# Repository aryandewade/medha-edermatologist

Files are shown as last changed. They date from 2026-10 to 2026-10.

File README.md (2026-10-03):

# Medha E-Dermatologist (Mobile Spacer Edition)

AI-assisted skin disease screening using standard smartphones fitted with an inexpensive 3D-printed optical spacer.

| File | Purpose |
|---|---|
| [prd.md](prd.md) | Product requirements: mobile-first user flow, clinical targets, triage priorities |
| [design.md](design.md) | UI/UX design: single-column mobile layout, spacer framing guide, touch controls |
| [architecture.md](architecture.md) | System architecture: mobile PWA, HTTPS ingress (Cloudflare Tunnel), FastAPI backend |
| [methodology.md](methodology.md) | ML methodology: EfficientNet-B0, mobile augmentations, calibration, triage rules |
| [data-plan.md](data-plan.md) | Clinical datasets (SCIN, Fitzpatrick17k, PAD-UFES-20, DDI), 6-class schema, collection protocol |
| [image-processing.md](image-processing.md) | Preprocessing details: quality gate, colour constancy, lesion localization, glare mitigation |
| [hardware-spacer.md](hardware-spacer.md) | Specifications for the 3D-printed optical spacer, phone cradle, hygiene, and reference patch |
| [api-spec.md](api-spec.md) | REST API contract between mobile PWA and backend (`/predict`, `/health`) |
| [testing-evaluation.md](testing-evaluation.md) | Test strategy, subgroup fairness evaluation, and demo-day hardware checklist |
| [setup-and-deployment.md](setup-and-deployment.md) | Local development setup, Cloudflare Tunnel HTTPS guide, mobile phone configuration |
| [ethics-and-safety.md](ethics-and-safety.md) | Mobile privacy, EXIF/GPS stripping, informed consent, triage ethics |
| [roadmap.md](roadmap.md) | Phased execution plan: mobile spacer first, USB dermatoscope multimodal later |

---

## One-Paragraph Summary
A frontline community health worker opens the web app on their smartphone over secure HTTPS, attaches a 3D-printed optical spacer to the phone's primary camera, places it flush against the patient's skin, and taps **Capture & Analyze**. The backend verifies sharpness and illumination, applies automatic colour constancy, localizes the central skin lesion, and evaluates a calibrated EfficientNet-B0 classifier across 6 classes: **Eczema, Psoriasis, Tinea (Ringworm), Acne, Healthy Skin, and Suspicious Lesions**. High-risk suspicious lesions immediately trigger an urgent specialist referral banner, while ambiguous or low-confidence presentations trigger an honest "uncertain, please consult a dermatologist" advisory.

---

## Read Order for New Team Members
`prd.md` ➔ `hardware-spacer.md` ➔ `image-processing.md` ➔ `architecture.md` ➔ `methodology.md` ➔ `roadmap.md`

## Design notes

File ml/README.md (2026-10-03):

# 6-Class Skin Disease Classifier (EfficientNet-B0)

Mobile-spacer skin screening: EfficientNet-B0 trained on smartphone + 3D-printed
optical spacer captures, with reference-patch colour calibration and calibrated
clinical triage.

## Supported Classes (6)
1. **Eczema** (Atopic Dermatitis)
2. **Psoriasis**
3. **Tinea** (Ringworm / fungal infection)
4. **Acne**
5. **Healthy Skin**
6. **Suspicious Lesion** (neoplastic / pre-cancerous — urgent referral)

---

## Workflow Architecture

```
[Smartphone + 3D-Printed Spacer]
          ↓
   Mobile PWA Capture (HTTPS)
          ↓
   Image Preprocessing
┌──────────────────────────────────────┐
│ • Quality Check (Blur / Glare / Illum)│
│ • Optional ROI Crop (Center Square)  │
│ • Resize to 224 × 224                │
│ • ImageNet Normalize                 │
└──────────────────┬───────────────────┘
                   ↓
         EfficientNet-B0 Backbone
          (ImageNet Pretrained)
                   ↓
      Custom Classifier Head
      (Dropout 0.3 + Linear 1280→6)
                   ↓
       6 Calibrated Output Classes
 ┌──────────┬───────────┬────────┬────────┬────────────┬──────────────────────┐
 ↓          ↓           ↓        ↓        ↓            ↓                      ↓
Eczema  Psoriasis   Tinea    Acne   Healthy   Suspicious Lesion     [Triage / Abstain]
```

---

## File Structure

- [`model.py`](src/model.py): `SkinDiseaseEfficientNetB0` PyTorch architecture with custom 6-class head and feature extraction.
- [`preprocess.py`](src/preprocess.py): Quality gate (Laplacian blur, glare, brightness), reference-patch colour constancy + Shades-of-Gray fallback, ROI cropping, 224x224 normalization.
- [`reference_patch.py`](src/reference_patch.py): 18% gray reference-patch locator + white balance (adaptive neutrality vs. skin baseline).
- [`inference.py`](src/inference.py): End-to-end triage engine (quality -> colour -> localization -> calibrated inference -> referral rules).
- [`dataset.py`](src/dataset.py): Dataset loader with mobile-appropriate augmentations and inverse class weighting.
- [`train.py`](src/train.py): Two-stage transfer learning (frozen warmup + unfrozen fine-tuning with cosine decay).
- [`calibrate.py`](src/calibrate.py): Temperature scaling (NLL fit + ECE) -> writes `backend/models/temperature.json`.
- [`eval.py`](src/eval.py): Per-class Precision/Recall/Macro-F1, confusion matrix (CSV+PNG), Top-3 accuracy, ECE, Fitzpatrick subgroup audit.
- [`data_harmonize.py`](src/data_harmonize.py): Ingest SCIN/Fitzpatrick17k/PAD-UFES-20 -> 6 canonical classes, pHash dedupe, group-safe stratified split + manifest.
- [`export_onnx.py`](src/export_onnx.py): ONNX model exporter for high-speed CPU inference.
- [`classes.yaml`](../configs/classes.yaml): Configuration defining class labels, colors, and clinical uncertainty thresholds.

---

## Quick Usage

All commands run from the `ml/` directory.

### 1. Harmonize datasets into the 6 canonical classes
```bash
python src/data_harmonize.py \
  --fitzpatrick_dir raw/fitzpatrick17k \
  --scin_dir raw/scin \
  --pad_dir raw/pad-ufes-20 \
  --local_dir raw/spacer_captures \
  --out_dir data --dedupe
```

### 2. Train / Fine-tune
Organize (or let step 1 produce) the dataset as:
```
data/
  train/<class>/*.jpg
  val/<class>/*.jpg
  test/<class>/*.jpg
```
Then run:
```bash
python src/train.py --train_dir data/train --val_dir data/val --finetune_epochs 20
```

### 3. Calibrate (temperature scaling)
```bash
python src/calibrate.py --checkpoint models/best_model.pt --val_dir data/val
```
Writes `backend/models/temperature.json`; the inference engine loads it automatically.

### 4. Evaluate (metrics + confusion matrix + fairness)
```bash
python src/eval.py --checkpoint models/best_model.pt --test_dir data/test --output_dir reports
```

### 5. Export to ONNX (for fast CPU inference)
```bash
python src/export_onnx.py --checkpoint models/best_model.pt --output models/model.onnx
```

### Reference-patch calibration (standalone check)
```bash
python src/reference_patch.py --image sample_capture.jpg
```

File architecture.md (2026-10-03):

# System Architecture (Mobile-First)

## 1. Overview
The architecture is designed as a **mobile-first client-server system**. A smartphone running a Progressive Web App (PWA) captures skin images through a 3D-printed optical spacer. The image and capture metadata are transmitted securely over HTTPS to a FastAPI inference backend that executes automated quality checks, colour constancy, lesion localization, model inference, and clinical triage rules.

```
+---------------------------------------+
|  Smartphone + 3D-Printed Spacer       |
|  Mobile Browser (React + Vite PWA)    |
|  - Rear camera (facingMode: environ)  |
|  - Live circular reticle & guide      |
|  - Canvas frame snapshot              |
+---------------------------------------+
                   │
                   │ POST /api/v1/predict
                   │ (Multipart JPEG + modality metadata)
                   │ Over HTTPS (Cloudflare Tunnel / ngrok / Cloud)
                   ▼
+-------------------------------------------------------+
|  FastAPI Backend Server                               |
|                                                       |
|  1. Ingestion & Validation (file type, size, EXIF)   |
|  2. Quality Gate (Laplacian blur, lighting, glare)    |
|  3. Colour Normalization (Gray-World / Patch balance) |
|  4. Lesion Localization (ROI crop & center-framing)   |
|  5. Preprocessing (Resize 224×224, ImageNet norm)     |
|  6. Inference Engine (ONNX Runtime / PyTorch)         |
|  7. Calibration & Uncertainty (T-scaling, OOD)        |
|  8. Clinical Triage Rules (Referral / Abstention)     |
|  9. Explainability (Grad-CAM++ heatmap overlay)       |
+-------------------------------------------------------+
                   │
                   │ JSON Result + Base64 Heatmap
                   ▼
+---------------------------------------+
|  Mobile Results View                  |
|  - Condition card & confidence score  |
|  - Top-3 differential breakdown       |
|  - Triage Referral Banner             |
|  - Heatmap visual overlay             |
+---------------------------------------+
```

---

## 2. Components & Responsibilities

| Component | Technology | Primary Responsibility |
|---|---|---|
| **Mobile Web Client** | React, Vite, Tailwind CSS, Lucide Icons | Touch-friendly camera feed, spacer framing guide, one-thumb capture, instant results display. |
| **Secure Ingress / Tunnel** | Cloudflare Tunnel / ngrok / Caddy HTTPS | Provides valid public SSL/TLS certificate required by mobile browsers for camera API access. |
| **API Server** | FastAPI, Uvicorn, Pydantic v2 | Endpoint orchestration, request validation, logging, and error handling. |
| **Quality Module** | OpenCV (`cv2`) | Fast assessment of motion blur, darkness, saturation, and reference patch detection. |
| **Colour & ROI Module** | OpenCV, NumPy | Colour constancy (Shades of Gray), background/spacer ring exclusion, and lesion bounding crop. |
| **Inference Engine** | ONNX Runtime (CPU) / PyTorch | High-throughput, low-latency evaluation of the trained EfficientNet-B0 network. |
| **Calibration Module** | NumPy, SciPy | Post-hoc temperature scaling ($T$) ensuring reliable, clinically calibrated probabilities. |
| **Triage Rules Engine** | Python | Maps probability vector to actionable clinical guidance (`ok`, `uncertain`, `urgent`). |
| **Explainability Engine**| PyTorch Grad-CAM | Generates morphological activation heatmaps confirming model attention. |

---

## 3. Data Flow (Single Mobile Capture)

1. **Client Capture:** User aligns the spacer flush against the skin. The video frame is snapped at native sensor resolution and encoded to JPEG (quality 0.92).
2. **Payload Submission:** `POST /api/v1/predict` sends:
   - `image`: Image binary (multipart/form-data)
   - `modality`: `"mobile_spacer"` (or `"dermatoscope"` in later phases)
   - `device_info`: Mobile handset model and browser agent
   - `capture_height_mm`: Distance from lens to skin (e.g. `35.0`)
3. **Quality Validation:** OpenCV computes Laplacian variance and mean brightness. If blurred or poorly lit, returns HTTP 422 with actionable guidance (e.g., `"Hold spacer steady against skin"`).
4. **Colour Normalization:** Calculates illumination cast using Gray-World or calibrated reference patch and standardizes color temperature across varied environments.
5. **Lesion Localization & ROI Cropping:** Identifies central lesion region, crops out the dark circular spacer borders, and resizes to $224 \times 224$ pixels.
6. **Inference & Calibration:** Evaluates ONNX model to produce raw logits $z_i$, then computes calibrated probabilities $p_i = \text{softmax}(z_i / T)$.
7. **Triage Assessment:**
   - If $P(\text{suspicious\_lesion}) \ge 0.25 \implies$ `urgent` triage alert.
   - If $\max_i P(i) < 0.50$ or $(P_1 - P_2) < 0.10 \implies$ `uncertain` triage alert.
   - Otherwise $\implies$ `ok` triage with condition name and reassurance advice.
8. **Client Display:** Renders triage alert banner, condition details, and top-3 distribution directly on the mobile screen.

---

## 4. Hosting & Network Topologies

Because **mobile browsers strictly forbid camera access on unencrypted HTTP connections** (except `localhost`, which a phone cannot access on an external machine), the hosting topology requires an HTTPS endpoint:

```
[Phone on 4G/Wi-Fi] 
         │
         ▼ (HTTPS: https://medha-demo.trycloudflare.com)
[Cloudflare Tunnel / ngrok Ingress]
         │
         ▼ (HTTP localhost:8000)
[FastAPI Backend on Dev Laptop]
```

| Deployment Mode | Ingress Strategy | Best Suited For |
|---|---|---|
| **Local Development with Phone** | **Cloudflare Tunnel (`cloudflared tunnel --url http://localhost:8000`)** or **ngrok** | Rapid live testing on physical smartphone with zero server cost. |
| **Local Wi-Fi Network** | Self-signed SSL certificate with local DNS or mkcert | Offline environments without active internet connection. |
| **Demo Day / Production** | Cloud Run or Render container with custom domain and managed SSL | High-reliability backup for hackathon jury evaluation. |

---

## 5. Configuration Architecture (`configs/classes.yaml`)

```yaml
modality: mobile_spacer
version: "v2.0-mobile"

classes:
  - id: eczema
    label: "Eczema"
    name: "Atopic Dermatitis / Eczema"
    severity: "common"
    color: "#2563EB"
  - id: psoriasis
    label: "Psoriasis"
    name: "Psoriasis"
    severity: "common"
    color: "#D97706"
  - id: tinea
    label: "Tinea"
    name: "Tinea / Fungal Ringworm"
    severity: "common"
    color: "#7C3AED"
  - id: acne
    label: "Acne"
    name: "Acne Vulgaris"
    severity: "common"
    color: "#059669"
  - id: healthy
    label: "Healthy Skin"
    name: "Normal Skin"
    severity: "normal"
    color: "#10B981"
  - id: suspicious_lesion
    label: "Suspicious Lesion"
    name: "Atypical / Neoplastic Lesion"
    severity: "urgent"
    color: "#DC2626"

thresholds:
  uncertain_max_prob: 0.50
  margin_min_prob: 0.10
  urgent_suspicious_prob: 0.25
  blur_min_laplacian_var: 55.0
  brightness_range: [40, 225]
  glare_max_ratio: 0.12
```

---

## 6. Security, Privacy & Data Protection

- **No EXIF Footprint:** Smartphone cameras embed exact GPS coordinates, timestamps, and device identifiers. The backend immediately strips all EXIF metadata in memory upon receiving the byte stream.
- **In-Memory Volatility:** Images are processed entirely within RAM buffers (`io.BytesIO`) and discarded upon request completion unless explicit user consent is flagged for model refinement.
- **Origin Isolation:** Strict CORS middleware allowing only the authorized frontend web origin.

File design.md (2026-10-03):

# Mobile UI/UX Design (Smartphone + 3D Spacer)

## 1. Design Principles
1. **One-Thumb Operation:** Primary actions (capture, retry, review) positioned in the natural thumb zone at the bottom of the screen.
2. **Physical-Digital Alignment:** Clear visual overlays guide the health worker to position the 3D spacer flush against the patient's skin.
3. **Clinical Triage Clarity:** Results emphasize triage action (Self-care/Monitor, Specialist Review, Urgent Referral) rather than raw disease probabilities.
4. **Resilient to Field Conditions:** Clear, actionable feedback on poor focus, inadequate light, or tilted spacer placement.

---

## 2. Mobile Screen Layout (Single-Column Vertical Flow)

```
+---------------------------------------+
|  [Logo] E-Dermatologist   [EN/HI/MR]  |
+---------------------------------------+
|                                       |
|  [Live Camera Viewfinder]             |
|   ┌─────────────────────────────┐     |
|   │       (  ( O )  )           │     |
|   │   Circular Spacer Reticle   │     |
|   │   & Lesion Framing Ring     │     |
|   │                             │     |
|   │ [• Ref Patch OK] [• Light OK]│    |
|   └─────────────────────────────┘     |
|                                       |
|  [Instructions Card]                  |
|  "Place spacer flat against skin.     |
|   Center the lesion inside circle."   |
|                                       |
|  [ CAPTURE & ANALYZE ] (Large Button) |
|  [ ⚡ Test Link ]   [ 📁 Upload Photo]|
+---------------------------------------+
|                                       |
|  [Triage Referral Banner]             |
|  🚨 URGENT REFERRAL RECOMMENDED       |
|                                       |
|  [Condition Summary Card]             |
|  Suspicious Lesion (78.4% Confidence) |
|                                       |
|  [Differential Distribution (Top-3)]  |
|  ■ Suspicious Lesion  78.4%           |
|  ■ Actinic / Psoriasis 14.1%          |
|  ■ Normal / Healthy    7.5%           |
|                                       |
|  [Analyzed Image with Heatmap Toggle] |
|                                       |
|  [ 📄 Export Referral Summary PDF ]   |
+---------------------------------------+
|  Footer: "Screening tool only. Not a  |
|  medical diagnosis. Consult doctor."  |
+---------------------------------------+
```

---

## 3. Core Mobile Components

| Component | Visual Presentation & Behavior |
|---|---|
| **Viewfinder & Spacer Reticle** | Full-width 4:3 or 1:1 camera feed showing a circular translucent framing ring matching the inner diameter of the 3D spacer cone. |
| **Placement & Lighting Chips** | Real-time visual status pills floating over the live feed: <br>• **Focus:** Green (`Sharp`) vs Amber (`Defocused - Press flush`) <br>• **Light:** Green (`Illumination OK`) vs Red (`Too dark`) <br>• **Reference Patch:** Green (`Patch Detected`) |
| **Primary Capture CTA** | Prominent floating action bar at bottom screen ($56\text{ px}$ height) with haptic feedback vibration on capture. |
| **Camera Selector (Streamlined)** | Automatically selects rear camera (`facingMode: environment`). An unobtrusive lens switch icon appears only if multiple rear lenses (e.g. macro vs wide) are detected. |
| **Instructions Bottom Sheet** | Expandable card explaining three-step physical placement: 1. Clean spacer contact rim. 2. Place flat against skin. 3. Tap Capture. |
| **Triage Alert Banners** | • **Urgent (Red):** `Possible serious or neoplastic lesion. Refer to dermatologist promptly.` <br>• **Uncertain (Amber):** `Image uncertain or ambiguous. Reposition spacer or consult doctor.` <br>• **Common Condition (Blue):** `Features consistent with [Condition]. Primary care management.` <br>• **Healthy (Green):** `No active lesion detected.` |
| **Heatmap & Contrast Slider** | Shows the preprocessed skin image with a toggleable Grad-CAM++ morphological activation overlay. |

---

## 4. UI States & Field Error Handling

| Scenario | User-Facing Guidance & Remediation |
|---|---|
| **Camera Permission Blocked** | Screen overlay explaining how to enable camera permissions in mobile browser settings. |
| **Tilted Spacer (Light Leak)** | Amber alert: *"Spacer not flat on skin. Light leakage detected. Press evenly against skin."* |
| **Motion Blur (Hand Shake)** | Red alert: *"Blurry capture. Rest arm on flat surface and hold phone steady."* |
| **Analyzing Pipeline** | Pulsing radial progress indicator with label: *"Normalizing colour and analyzing..."* (Buttons disabled). |
| **Offline / Network Interruption** | Offline cache badge: *"Unable to reach server. Check connection or tap Retry."* |
| **Gallery Upload Fallback** | Subordinate link beneath capture button allowing selection of existing photo from mobile camera roll. |

---

## 5. Visual Styling & Mobile Ergonomics

- **Palette:** Clinical Trust theme. Deep navy header (`#0F172A`), clean off-white background (`#F8FAFC`), crisp high-contrast cards (`#FFFFFF`).
- **Severity Semantic Colors:**
  - Urgent Referral: Crimson (`#DC2626`)
  - Review / Common: Cobalt Blue (`#2563EB`)
  - Healthy Skin: Emerald Green (`#059669`)
  - Warning / Uncertain: Warm Amber (`#D97706`)
- **Typography:** System sans-serif (`Inter`, `-apple-system`, `Roboto`) for instantaneous rendering on mobile devices.
- **Accessibility:**
  - Minimum touch targets of $48 \times 48\text{ px}$ across all interactive buttons.
  - WCAG AAA contrast ratio ($\ge 7:1$) on triage advisory text.
  - Dynamic type support for larger font sizes.

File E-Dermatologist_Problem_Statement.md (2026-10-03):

# E-Dermatologist: Skin Disease Screening System

**Hackathon:** Somaiya Vidyavihar University, K J Somaiya School of Engineering  
**Clinical Partner:** Kaushalya Hospital  
**Document Type:** Problem statement and project brief (Mobile Spacer Edition)

---

## 1. Problem Statement

Access to dermatologists is severely restricted across rural and semi-urban India. Frontline community health workers (such as ASHA workers and local nurses) encounter high volumes of unmanaged or misidentified skin conditions, while patients often travel vast distances or delay care for months until manageable conditions worsen or malignant lesions advance.

Build a low-cost, mobile-first **AI skin disease screening and clinical triage system** that pairs standard **smartphones with an inexpensive 3D-printed optical spacer**. A health worker attaches the spacer to their phone camera, places it flush against the patient's skin, and captures a standardized close-up photo. The system checks capture sharpness, normalizes illumination and colour, localizes the lesion, and reports the likely condition category, confidence score, and top-3 differential breakdown to facilitate immediate primary care management or expedited referral to a dermatologist.

---

## 2. Objectives

1. Enable **instant mobile browser screening** on standard smartphones via a responsive Progressive Web App over secure HTTPS.
2. Standardize photographic capture using an accessible, **3D-printed focal spacer** that eliminates hand tremor focus shifts and standardizes distance.
3. Classify skin images across **common outpatient conditions** (Eczema, Psoriasis, Tinea, Acne), **Healthy Skin**, and a dedicated **Suspicious Lesion** triage class.
4. Normalize real-world lighting variations using automated **colour constancy** and reference patch calibration.
5. Provide **honest clinical triage guidance**: flag suspicious lesions for urgent referral and abstain on ambiguous or low-confidence cases.
6. Serve as an accessible **screening and triage decision aid**, explicitly complementing rather than replacing medical doctors.

---

## 3. Supported Clinical Classes

| Category | Conditions Included | Primary Triage Recommendation |
|---|---|---|
| **Inflammatory** | Eczema (Atopic Dermatitis), Psoriasis, Acne Vulgaris | Primary clinic management / Symptom monitoring |
| **Fungal Infection** | Tinea (Ringworm / Dermatophytosis) | Antifungal treatment / Hygiene guidance |
| **Normal Baseline** | Healthy Skin | Reassurance |
| **High-Risk Lesions** | Suspicious Neoplastic Lesions (Melanoma, BCC, SCC, Actinic Keratosis) | **Urgent Dermatologist Referral & In-Person Review** |

*(Future Phase: Specialized Dermatoscope Modality for fine-grained sub-classification of melanocytic and non-melanocytic lesions).*

---

## 4. Scope

**In Scope:**
- Mobile-first web interface (PWA) with live viewfinder framing guide.
- Standardized capture with 3D-printed spacer and reference colour patch.
- Secure HTTPS tunneling (Cloudflare Tunnel) connecting mobile phones to the backend.
- Backend image processing pipeline: blur/glare quality gate, colour constancy, lesion localization.
- Multi-class classification via fine-tuned EfficientNet-B0.
- Confidence calibration (Temperature Scaling) and urgent referral rules.
- Morphological explainability via Grad-CAM++ activation heatmaps.

**Out of Scope (Hackathon Prototype):**
- Definitive clinical diagnosis or automated prescription dispensing.
- Invasive cancer staging or replacing dermatopathological biopsy.
- Long-term Electronic Medical Record (EMR) persistent storage.
- Ultra-rare skin pathologies outside the supported taxonomy.

---

## 5. Hardware Specifications

| Item | Specification | Status |
|---|---|---|
| **Smartphone** | Standard rear autofocus camera (e.g. 12MP+ sensor, iOS or Android) | Required (Primary) |
| **3D-Printed Spacer** | Fixed 35 mm focal height, matte-black non-reflective interior, phone clip | Required (Primary) |
| **Reference Patch** | Dual 18% neutral gray & 90% white patch with 5 mm scale bar | Required (Primary) |
| **Hygiene Supplies** | 70% isopropyl alcohol sanitization wipes for spacer contact rim | Required |
| **Laptop / Compute** | 8 GB+ RAM for running backend inference (CPU inference via ONNX) | Required |
| **Network Ingress** | Cloudflare Tunnel or ngrok providing public HTTPS endpoint | Required |
| **USB Dermatoscope** | Handheld UVC microscope camera (for secondary multimodal phase) | Phase 2 Extension |

---

## 6. Software Stack

- **Frontend:** React, Vite, Tailwind CSS, HTML5 Canvas API, Mobile WebRTC (`getUserMedia`).
- **Networking:** Cloudflare Tunnel (`cloudflared`) / ngrok for mobile HTTPS camera access.
- **Backend:** FastAPI (Python 3.10+), Uvicorn, Pydantic v2.
- **Image Processing & Vision:** OpenCV (`cv2`), NumPy, SciPy (colour constancy, Otsu segmentation, Laplacian sharpness).
- **ML Framework & Serving:** PyTorch, Torchvision, ONNX Runtime (CPU-optimized), Albumentations.

---

## 7. System Workflow

```
[Smartphone + 3D Spacer] ──(HTTPS)──> [FastAPI Backend]
                                             │
                                  ├─ 1. Quality Validation (Blur, light, glare)
                                  ├─ 2. Colour Constancy (Shades of Gray)
                                  ├─ 3. Lesion Localization (ROI square crop)
                                  ├─ 4. EfficientNet-B0 ONNX Inference
                                  ├─ 5. Calibrated Triage Rules
                                  └─ 6. Grad-CAM++ Morphological Overlay
                                             │
                                      (JSON Result)
                                             ▼
                             [Mobile Results & Referral View]
```

---

## 8. Disclaimer
This software is a screening decision-support aid and does not constitute a definitive medical diagnosis. All patients presenting with persistent, worsening, or suspicious skin lesions must be referred to a qualified dermatologist.

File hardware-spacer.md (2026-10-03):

# Hardware Specification: 3D-Printed Optical Spacer

## 1. Purpose & Physical Rationale

Standard smartphone cameras cannot reliably photograph close-up skin lesions because:
1. **Uncontrolled Focal Distance:** Hand tremor and micro-movements cause autofocus hunting, yielding blurred captures.
2. **Variable Illumination & Glare:** Direct camera flash causes harsh specular reflection (white hot spots) that obscures lesion pigment networks and texture.
3. **Scale Ambiguity:** Without a physical scale reference, machine learning models cannot discern the true physical dimensions of a lesion (e.g., a 2 mm macule vs. a 15 mm patch).

The **3D-Printed Optical Spacer** physically clips onto the smartphone to establish a **fixed, repeatable optical focal plane**, control ambient illumination, and present a calibrated scale and colour reference in every capture.

---

## 2. Spacer Design Specifications

```
             [Smartphone Body]
        ═══════════════════════════
                 [Lens]
                   │  (Aperture Ø 14 mm)
           ┌───────┴───────┐
           │   Top Collar  │
           │               │
           │  Conical Tube │  ◄── Matte Black Interior
           │  (Height:     │      (Roughness Ra > 3.2 µm)
           │   35 mm)      │
       ┌───┴───────────────┴───┐
       │   Contact Ring Flange │  ◄── Radius 24 mm
       │ [Ref Patch] [5mm Bar] │
       └───────────────────────┘
        ═══════════════════════════
               [Patient Skin]
```

### Physical Dimensions
- **Focal Height ($H$):** $35.0\text{ mm}$ (optimal for standard smartphone wide lenses having a minimum focus distance of $50\text{–}70\text{ mm}$ with $1.5\times$ digital macro framing, or $35\text{ mm}$ for lenses with near-macro autofocus).
- **Optional Stackable Rings:** Modular $5\text{ mm}$ snap-fit extension rings to adjust total focal height from $30\text{ mm}$ to $50\text{ mm}$ depending on the specific handset camera module.
- **Top Camera Aperture:** $14.0\text{ mm}$ diameter, oversized to clear multi-lens camera bumps without vignetting.
- **Base Skin Contact Diameter:** $48.0\text{ mm}$ outer diameter ($38.0\text{ mm}$ inner clear aperture) to capture adequate lesion margins.

---

## 3. Optical & Lighting Control

- **Matte-Black Interior Wall:**
  - The interior conical surface must feature a **dead-matte black finish** to eliminate internal specular reflections and barrel flaring.
  - Sliced with internal concentric micro-grooves ($0.2\text{ mm}$ step height) to trap grazing-angle light rays.
- **Ambient Lighting Ports:**
  - Includes two angled, translucent diffuser side windows ($45^\circ$ angle of incidence) covered with white diffusion film.
  - Allows ambient clinic room light to illuminate the lesion softly and uniformly while completely blocking direct glare and shadowing from the phone handset.
- **Flash Lockout:** The spacer collar physically occludes the smartphone's built-in LED flash to prevent accidental flash blinding.

---

## 4. Materials, Hygiene & Biocompatibility

- **Filament Material:** **PETG** (Polyethylene Terephthalate Glycol) or **Medical-Grade PLA**.
  - High chemical resistance against alcohol and disinfectants.
  - Biocompatible for transient non-broken skin contact (ISO 10993 compliant).
- **Sanitization Protocol:**
  - The skin-contact flange must be thoroughly wiped with a **70% Isopropyl Alcohol (IPA)** disinfectant wipe before and after every patient contact.
  - PETG maintains dimensional integrity and does not craze or degrade after repeated alcohol wipe exposure.
- **Wall Thickness:** $2.0\text{ mm}$ minimum to guarantee mechanical rigidity and prevent ambient light bleeding through the plastic walls.

---

## 5. Calibrated Reference Patch Integration

Mounted flush along the interior lower rim of the contact aperture:
1. **18% Neutral Gray Card Segment:** Provides ground-truth neutral reflectance for automatic white balance and colour constancy algorithms.
2. **90% Reflective White Patch:** Defines maximum dynamic range and detects LED overexposure.
3. **5 mm High-Contrast Scale Bar:** Alternating black/white $1.0\text{ mm}$ millimeter ticks enabling pixel-to-millimeter spatial calibration.

---

## 6. Phone Cradle & Handset Compatibility

The spacer mounts to the handset via an adjustable spring-loaded clamping bracket or model-specific snap-on phone case:

| Phone Model | Primary Lens Position | Min. Focus Distance | Recommended Spacer Height |
|---|---|---|---|
| **Samsung Galaxy S22 / S23 / S24** | Center-left top lens (50MP 1x wide) | $45\text{ mm}$ | $35\text{ mm}$ (with $1.2\times$ crop) |
| **iPhone 13 / 14 / 15 (Standard)** | Bottom-left lens (1x wide) | $50\text{ mm}$ | $35\text{ mm}$ |
| **iPhone 13 / 14 / 15 Pro** | Bottom-left lens (locked to 1x wide) | $40\text{ mm}$ (disable macro auto-switch) | $35\text{ mm}$ |
| **OnePlus 11 / 12 / Nord** | Upper central circular cluster | $50\text{ mm}$ | $40\text{ mm}$ |
| **Google Pixel 7 / 8** | Horizontal camera bar (left lens) | $45\text{ mm}$ | $35\text{ mm}$ |

---

## 7. 3D Print Settings (FDM / SLA)

```ini
Layer Height: 0.16 mm (for smooth internal micro-grooves)
Infill Density: 100% (Solid, to block light transmission)
Perimeters / Shells: 4
Material: Black PETG (Matte preferred)
Nozzle Temp: 235°C
Bed Temp: 75°C
Supports: None required (designed with 45° overhang angle)
Post-Processing: Wipe interior with isopropyl alcohol; apply matte black acrylic spray if glossy filament was used.
```

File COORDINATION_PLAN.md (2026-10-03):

# Dual-Agent Simultaneous Development & Coordination Plan

**Project:** E-Dermatologist (Mobile Spacer Edition)  
**Coordination Strategy:** Strict modular separation with immutable interface contracts to enable simultaneous, conflict-free development.

---

## 1. Modular Division of Labor

```
┌─────────────────────────────────────────────────────────────┐
│                    SHARED CONTRACTS                         │
│  • configs/classes.yaml (Class Schema & Thresholds)         │
│  • api-spec.md          (REST API Data Contracts)           │
│  • models/model.onnx    (Shared Model Weights Artifact)     │
└──────────────────────────────┬──────────────────────────────┘
                               │
               ┌───────────────┴───────────────┐
               ▼                               ▼
┌──────────────────────────────┐┌──────────────────────────────┐
│  AGENT 1: ANTIGRAVITY        ││  AGENT 2: PARTNER AGENT      │
│  (Frontend, UX & Reporting)  ││  (ML, Vision & Hardware)     │
├──────────────────────────────┤├──────────────────────────────┤
│ • Mobile PWA UI & Viewfinder ││ • Data Harmonization (SCIN/  │
│ • i18n (EN, HI, MR strings)  ││   Fitzpatrick17k/PAD-UFES)   │
│ • PDF Referral Report Export ││ • Reference Patch CV Module  │
│ • Backend /report Endpoint   ││ • Temperature Calibration (T)│
│ • Client State & History     ││ • Evaluation Script & Matrix │
│ • Touch Ergonomics & Audio   ││ • 3D CAD Spacer STL Generator│
└──────────────────────────────┘└──────────────────────────────┘
```

---

## 2. Strict File Ownership Matrix

Neither agent should edit files owned by the other without explicit coordination.

| Subsystem / Directory | Owner | Permitted Actions |
|---|---|---|
| `frontend/src/**` | **Agent 1 (Antigravity)** | Read/Write (Components, styling, i18n, PDF export) |
| `backend/app/services/report.py` | **Agent 1 (Antigravity)** | Read/Write (ReportLab PDF generation service) |
| `ml/src/data_harmonize.py` | **Agent 2 (Partner)** | Read/Write (Dataset downloading and label mapping) |
| `ml/src/calibrate.py` | **Agent 2 (Partner)** | Read/Write (Temperature scaling optimization) |
| `ml/src/eval.py` | **Agent 2 (Partner)** | Read/Write (Confusion matrix, subgroup fairness) |
| `ml/src/reference_patch.py` | **Agent 2 (Partner)** | Read/Write (OpenCV reference patch locator) |
| `hardware/**` | **Agent 2 (Partner)** | Read/Write (3D print CAD, STL generators, scale bars) |
| `configs/classes.yaml` | **SHARED (Frozen)** | Read-Only unless mutually agreed in this document |
| `backend/app/routers/predict.py`| **SHARED (Careful)** | Agent 1 owns `/report`; Agent 2 integrates CV patch |

---

## 3. Simultaneous Task Schedule

### Agent 1 (Antigravity) Work Queue:
- [x] **Task 1.1:** Build `backend/app/services/report.py` using ReportLab to generate a clean, 1-page clinical referral PDF.
- [x] **Task 1.2:** Add `POST /api/v1/report` endpoint to `backend/app/routers/predict.py` returning binary PDF.
- [x] **Task 1.3:** Implement Hindi (`hi`) and Marathi (`mr`) full translation dictionaries in `frontend/src/i18n.ts`.
- [x] **Task 1.4:** Connect the **PDF Export** button in `ResultsDashboard.tsx` to download the generated report.
- [x] **Task 1.5:** Add local session history drawer (allowing health workers to review previous captures).

### Agent 2 (Partner Agent) Work Queue:
- [x] **Task 2.1:** Create `ml/src/data_harmonize.py` to ingest and map SCIN, Fitzpatrick17k, and PAD-UFES-20 into the 6 canonical classes.
- [x] **Task 2.2:** Build `ml/src/reference_patch.py` using OpenCV template/color matching to locate the 18% gray patch in the spacer margin.
- [x] **Task 2.3:** Build `ml/src/calibrate.py` to optimize temperature $T$ on validation logits and output `backend/models/temperature.json`.
- [x] **Task 2.4:** Build `ml/src/eval.py` computing per-class Precision, Recall, Macro-F1, and Confusion Matrix.
- [x] **Task 2.5:** Create `hardware/spacer_generator.py` (or OpenSCAD script) generating parameterized 35mm optical spacer STL models.

---

## 4. Live Status Tracker

| Task ID | Description | Assigned To | Status | Notes |
|---|---|---|---|---|
| **1.1** | ReportLab PDF referral generator service | Agent 1 (Antigravity) | `COMPLETED` | Generates 1-page PDF summary |
| **1.2** | `POST /api/v1/report` backend endpoint | Agent 1 (Antigravity) | `COMPLETED` | Endpoint verified with HTTP 200 |
| **1.3** | Hindi & Marathi i18n dictionaries | Agent 1 (Antigravity) | `COMPLETED` | Dynamic EN/HI/MR switcher active |
| **1.4** | PDF export button integration in React UI | Agent 1 (Antigravity) | `COMPLETED` | One-touch PDF download |
| **1.5** | Session history drawer in mobile UI | Agent 1 (Antigravity) | `COMPLETED` | Stores last 8 captures in session |
| **2.1** | `ml/src/data_harmonize.py` mapping pipeline | Agent 2 (Partner) | `COMPLETED` | 6-class label map, pHash dedupe, group-safe stratified split, manifest |
| **2.2** | `ml/src/reference_patch.py` locator | Agent 2 (Partner) | `COMPLETED` | Adaptive gray-patch WB; integrated into `preprocess.py` + `inference.py` + `/predict` |
| **2.3** | `ml/src/calibrate.py` temperature scaling | Agent 2 (Partner) | `COMPLETED` | ECE + scipy T-fit; writes `backend/models/temperature.json`; loaded by engine |
| **2.4** | `ml/src/eval.py` metrics and matrix | Agent 2 (Partner) | `COMPLETED` | Precision/Recall/Macro-F1, CM (CSV+PNG), Top-3, ECE, Fitzpatrick audit |
| **2.5** | 3D spacer parametric CAD script | Agent 2 (Partner) | `COMPLETED` | `hardware/spacer_generator.py` + `spacer.scad`; watertight STL in `hardware/stl/` |

---

## 5. Clean Interface Contracts for Agent 2

To start work immediately without conflicts, Agent 2 should follow these exact interfaces:

### Interface 1: Reference Patch Detector (`ml/src/reference_patch.py`)
```python
def detect_and_calibrate_patch(image_bgr: np.ndarray) -> Tuple[np.ndarray, bool, Dict[str, Any]]:
    """
    Returns:
      corrected_bgr: Normalized image array
      patch_found: True if 18% gray patch was located on spacer margin
      metrics: {"gray_deviation": float, "patch_coords": [x, y, w, h]}
    """
```

### Interface 2: Temperature Calibration Output (`backend/models/temperature.json`)
```json
{
  "temperature": 1.25,
  "ece_before": 0.124,
  "ece_after": 0.038,
  "calibrated_at": "2026-10-03"
}
```

### Interface 3: Hardware CAD (`hardware/`)
Create `hardware/spacer_generator.py` or `.scad` to output STL files into `hardware/stl/`.

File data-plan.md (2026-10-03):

# Data Plan (Mobile Spacer-First)

## 1. Class Set (Mobile Clinical Profile)

The classification schema focuses on common outpatient conditions treatable at primary health centers, plus a healthy skin baseline and a critical referral category for suspicious neoplastic lesions.

| ID | Condition / Category | Primary Clinical Sources | Triage Action |
|----|---|---|---|
| `eczema` | Eczema (Atopic Dermatitis) | DermNet, Fitzpatrick17k, SCIN, SD-198 | Primary care treatment / Monitor |
| `psoriasis` | Psoriasis | DermNet, Fitzpatrick17k, SCIN, SD-198 | Primary care treatment / Specialist triage |
| `tinea` | Tinea (Ringworm / Fungal) | DermNet, Fitzpatrick17k, SCIN | Antifungal treatment / Monitor |
| `acne` | Acne Vulgaris | DermNet, Fitzpatrick17k, SCIN, SD-198 | Primary care treatment |
| `healthy` | Healthy Skin | Own spacer captures, normal skin regions | Reassurance |
| `suspicious_lesion` | Suspicious Lesion (Melanoma, BCC, SCC, Actinic Keratosis) | DDI, PAD-UFES-20, Fitzpatrick17k, SCIN | **Urgent Dermatologist Referral** |

*Note on `suspicious_lesion`:* Rather than forcing a mobile phone camera to reliably sub-classify subtle histological differences between early melanoma, nodular BCC, and invasive SCC without dermoscopy, these high-risk neoplastic and pre-malignant lesions are pooled into a single high-sensitivity referral class. A specialized dermatoscope modality can be added later for deep lesion subtyping.

---

## 2. Source Datasets (Clinical & Smartphone Photography)

Dermoscopy datasets (HAM10000, ISIC) are replaced with clinical and smartphone macro photography datasets reflecting realistic mobile optical characteristics:

| Dataset | Modality & Description | Key Assets | Considerations & Caveats |
|---|---|---|---|
| **Fitzpatrick17k** | Clinical & patient-captured skin photos | 16,577 images labeled with condition and Fitzpatrick skin type (FST I–VI) | Atlases web-scraped; labels have minor noise; deduplicate carefully |
| **SCIN (Google)** | Smartphone photos crowdsourced in real-world settings | Real mobile sensors, diverse lighting, includes healthy/mild cases | Free-form framing; requires lesion cropping and quality filtering |
| **PAD-UFES-20** | Smartphone cameras (various models) | 2,298 clinical images with biopsy labels and patient metadata | Includes smartphone photos of suspicious lesions and inflammatory diseases |
| **DDI (Diverse Dermatology Images)** | Clinical photography from Stanford | High-quality clinical photos across Fitzpatrick I–VI with biopsy ground truth | Excellent benchmark for fairness and suspicious lesion sensitivity |
| **DermNet NZ** | Clinical photography atlas | Extensive visual coverage of inflammatory and fungal conditions | Check licensing; resolution varies; standard clinical perspective |
| **SD-198** | Clinical digital photography | 198 disease classes, 6,585 images | Good supplemental source for acne, eczema, and psoriasis variations |
| **Own Spacer Captures** | Smartphone + 3D-printed spacer + reference patch | Exact hardware domain target for calibration and validation | Primary benchmark for model selection, thresholding, and demo stability |

---

## 3. Label Harmonization & Mapping

1. **Master Dictionary (`ml/data/label_map.csv`):** Maps thousands of raw source tags into the 6 canonical target IDs (`eczema`, `psoriasis`, `tinea`, `acne`, `healthy`, `suspicious_lesion`).
2. **Suspicious Lesion Grouping:**
   - Includes: Melanoma, Basal Cell Carcinoma (BCC), Squamous Cell Carcinoma (SCC), Actinic Keratosis (AK), Atypical/Dysplastic Nevi with malignant suspicion.
   - Excludes: Benign regular nevi, seborrheic keratosis, and common freckles (filtered or routed to healthy/benign where verified).
3. **Ambiguity Handling:** Any image with conflicting multi-disease tags or low diagnostic confidence is discarded.

---

## 4. Data Cleaning & Normalization Pipeline

1. **Perceptual Deduplication:** Run perceptual hashing (pHash and dHash, Hamming distance $\le 4$) across all merged datasets to eliminate duplicates and near-identical crops that could bridge train and test sets.
2. **Artifact & Non-Skin Rejection:** Automatically detect and discard images with non-skin subjects, watermarks, intrusive text, or black borders.
3. **Lesion Localization & Standardized Cropping:**
   - Detect skin ROI and center crop/crop around lesion bounding boxes.
   - Standardize aspect ratios to prevent unnatural stretching.
4. **Colour & Illumination Normalization:**
   - Apply Gray-World or Shades-of-Gray colour constancy to correct varied hospital/room lighting casts before training.

---

## 5. Dataset Splits

| Split | Proportion | Splitting Strategy |
|---|---|---|
| **Train** | 70% | Stratified by class and grouped by patient/source ID to prevent data leakage. |
| **Validation** | 15% | Used for hyperparameter tuning, early stopping, and temperature scaling calibration. |
| **Public Test** | 15% | Held out for benchmark evaluation. |
| **Real Spacer Test Set** | Separate (Held-out) | Real photos captured with the project smartphone and 3D spacer. Serves as the ultimate ground-truth decision gate. |

---

## 6. Real-Camera Spacer Data Collection Protocol

To eliminate domain shift and calibrate the mobile model on the physical hardware:

### Hardware Setup
- **Smartphone:** Standardized test model (e.g., primary camera, 1x focal length, autofocus locked/set to spacer height, flash disabled, ambient room lighting or internal spacer diffuse LED).
- **3D-Printed Spacer:** Fixed height (e.g., 35 mm distance from camera lens to skin plane), matte-black non-reflective interior.
- **Reference Patch:** A calibrated dual-color/gray reference ring (18% neutral gray, 90% white patch, and 5 mm scale bar) mounted at the spacer contact perimeter to calibrate scale and white balance.

### Collection Procedure
1. **Healthy Skin Targets:**
   - Minimum 100 captures across 10+ diverse individuals covering Fitzpatrick types III to VI.
   - Body sites: Inner forearm, outer arm, dorsal hand, cheek, forehead, neck.
   - 3 captures per site (repositioned between shots).
2. **Clinical Lesions (Hospital Collaboration):**
   - Conducted exclusively under clinician supervision at Kaushalya Hospital.
   - **Mandatory written informed consent** signed before capturing.
   - Record anonymous metadata: Unique ID, age band, sex, anatomical site, clinician ground truth, Fitzpatrick skin type, and reference patch visibility.
3. **Sanitization:** Disinfect the spacer contact ring with hospital-grade 70% isopropyl alcohol wipes between every patient.
4. **Data Hygiene:** Strip all EXIF metadata, GPS coordinates, device serial numbers, and timestamp identifiers before ingest into the training/eval folders.

---

## 7. Class Balance Targets & Bias Auditing

- **Training Distribution Target:** Aim for at least 800 training samples per class; floor of 300 samples for the `suspicious_lesion` cluster.
- **Class Imbalance Strategy:** Use inverse frequency class weighting and Focal Loss ($\gamma = 2.0$) to avoid bias toward frequent inflammatory conditions.
- **Fairness & Subgroup Audits:**
  - Evaluate accuracy, recall, and calibration error across Fitzpatrick skin type buckets: Fair (I–II), Intermediate (III–IV), and Deeply Pigmented (V–VI).
  - Safety requirement: Recall for `suspicious_lesion` must remain $\ge 0.90$ across all available skin-tone cohorts.

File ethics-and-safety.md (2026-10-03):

# Ethics, Safety, and Responsible AI Use (Mobile Spacer Edition)

## 1. Clinical Intended Use
E-Dermatologist is an **AI-assisted screening and triage decision-support tool** intended for use by trained frontline health workers. It is **not** a diagnostic device, does not prescribe medications, and does not replace in-person consultation with a qualified dermatologist.

---

## 2. Patient Privacy & Data Hygiene on Mobile Handsets

Capturing clinical photographs using mobile smartphones introduces privacy challenges requiring strict controls:

1. **Immediate EXIF & GPS Stripping:**
   - Smartphone camera sensors automatically attach high-precision GPS coordinates, exact timestamps, handset serial numbers, and device hardware signatures.
   - The system immediately strips all EXIF metadata in memory before parsing pixel arrays. No geographic or device data is retained or logged.
2. **Zero-Local-Footprint Default:**
   - Captured frames are held temporarily in the browser canvas and transmitted over HTTPS in volatile memory.
   - Images are **never saved to the smartphone's native camera roll or photo gallery**, preventing accidental exposure on personal or shared clinic devices.
3. **In-Memory Server Processing:**
   - The backend server processes image streams directly in RAM (`io.BytesIO`). No patient photos are written to server disks unless the patient has explicitly signed an IRB-approved consent form for model improvement.
4. **Third-Party Isolation:**
   - Patient photographs are never transmitted to external commercial vision APIs or cloud language models.

---

## 3. Informed Consent Protocol for Mobile Photography

Whenever taking skin photographs for screening or evaluation:

- **Verbal Explanation:** The health worker must explain in the patient's primary language that the phone camera with the plastic spacer will take a close-up photo of the affected skin patch to assist with screening.
- **Voluntary Participation:** The patient must be informed that screening is completely voluntary and refusal will not compromise their care.
- **Personal Phone Safeguard:** If health workers utilize personal mobile devices in the field, they must use the secure web client rather than taking standard photos via their phone camera app.

---

## 4. Safety Architecture & Clinical Referral Guidance

| Clinical Scenario | System Triage Wording | Clinical Action Required |
|---|---|---|
| **Suspicious Neoplastic Lesion** | *"Morphological features warrant formal in-person examination by a dermatologist. Facilitate prompt referral."* | Expedited clinic appointment at Kaushalya Hospital; avoid premature biopsy or delay. |
| **Common Inflammatory / Fungal** | *"Features consistent with [Condition]. Consider clinical confirmation and primary care management."* | Primary clinic treatment protocol (e.g. topical emollients, antifungals). |
| **Ambiguous / Borderline** | *"Uncertain presentation. Please consult a dermatologist for manual examination."* | Abstains from guessing; prevents false reassurance or incorrect self-medication. |
| **Healthy Skin** | *"No active inflammatory or suspicious lesion detected."* | Patient reassurance. |

*Absolute Wording Rule:* The interface must **never** state *"You have [Disease]"* or *"Diagnosis: [Disease]"*. All findings are phrased as screening suggestions.

---

## 5. Algorithmic Fairness & Bias Mitigation

- **Skin Tone Diversity:** Benchmark performance across Fitzpatrick skin types I through VI. Avoid claiming universal accuracy without explicit stratified metrics.
- **Disproportionate Risk:** In deeply pigmented skin (Fitzpatrick V–VI), erythema (redness) often presents as violaceous, brown, or hyperpigmented patches. Training data and evaluation must account for these presentations to avoid under-detecting eczema and psoriasis in Indian patient populations.
- **Model Card Disclosure:** Maintain an open model card documenting dataset distributions, training parameters, subgroup recall, and known failure modes.

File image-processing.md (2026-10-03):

# Digital Image Processing Pipeline (Mobile Spacer Photography)

This document details the complete computer vision and digital image processing pipeline executed prior to model inference. Because frontline smartphone photos suffer from varied illuminants, hand tremors, and skin reflections, this preprocessing sequence transforms noisy field captures into standardized, normalized clinical inputs.

---

## 1. High-Level Processing Architecture

```
Raw Smartphone Frame (JPEG, 12MP / 4032×3024)
                      │
                      ▼
        [Stage 1: Quality Gate & Validation]
        ├─ Laplacian Sharpness (Var ≥ 55.0)
        ├─ Illumination Range ([40, 225])
        ├─ Glare / Specular Hotspot Ratio (≤ 12%)
        └─ Reference Patch Detection
                      │ (PASS)
                      ▼
        [Stage 2: Colour Constancy & Normalization]
        ├─ Shades-of-Gray Illuminant Estimation (p=6)
        └─ Reference Patch Alignment (Gray R=G=B)
                      │
                      ▼
        [Stage 3: Lesion Localization & ROI Segmentation]
        ├─ Spacer Rim & Background Masking
        ├─ Skin Thresholding (YCbCr / HSV)
        ├─ Primary Lesion Bounding Box
        └─ Aspect-Ratio Preserving Square Crop
                      │
                      ▼
        [Stage 4: Tensor Standardization]
        ├─ Bicubic Resize to 224 × 224
        └─ ImageNet Normalization (Mean / Std)
                      │
                      ▼
        To EfficientNet-B0 Backbone (1, 3, 224, 224)
```

---

## 2. Stage 1: Quality Gates & Automated Validation

Images failing physical capture criteria are rejected immediately with actionable guidance before consuming ML inference cycles:

### A. Blur & Defocus Estimation (Laplacian Variance)
The Laplacian operator $\nabla^2 I$ computes the second-order spatial derivatives of pixel intensities:
$$\nabla^2 I = \frac{\partial^2 I}{\partial x^2} + \frac{\partial^2 I}{\partial y^2}$$
Sharp edges exhibit high spatial variance, whereas defocused or motion-blurred frames exhibit low variance:
$$\text{Blur Score} = \text{Var}\left( \nabla^2 I_{\text{gray}} \right) = \frac{1}{N} \sum_{x,y} \left( \nabla^2 I(x,y) - \mu_{\nabla^2} \right)^2$$
- **Threshold:** $\text{Blur Score} \ge 55.0$ (Pass). If $< 55.0$, return HTTP 422: `"Image too blurry. Hold spacer steady against skin."`

### B. Illumination & Dynamic Range
- Convert to grayscale $I_{\text{gray}}$. Calculate mean intensity $\mu_I$.
- **Acceptance Window:** $40 \le \mu_I \le 225$.
- Images $< 40$ are underexposed (insufficient clinic lighting); images $> 225$ are overexposed.

### C. Specular Glare & Reflection Ratio
Moist or oily skin reflects direct light rays, producing blinding saturated white spots ($I \ge 245$ across all channels):
$$\text{Glare Ratio} = \frac{\sum \mathbb{I}(I_{\text{gray}} \ge 245)}{N_{\text{total}}}$$
- **Threshold:** $\text{Glare Ratio} \le 0.12$ ($12\%$). If higher, the user is prompted to tilt the spacer slightly to dissipate direct specular bounce.

---

## 3. Stage 2: Colour Constancy & Illumination Normalization

Smartphone cameras apply proprietary Auto White Balance (AWB) algorithms that alter skin tones under fluorescent, halogen, or warm LED lighting. We apply physical colour constancy to extract the true skin reflectance:

### A. Shades-of-Gray Algorithm
Generalizes the Gray-World ($p=1$) and White-Patch ($p=\infty$) hypotheses using the Minkowski $p$-norm ($p=6$):
$$e_c = \left( \frac{1}{|A|} \int_{x \in A} |I_c(x)|^p dx \right)^{1/p}, \quad c \in \{R, G, B\}$$
The estimated illuminant vector $\mathbf{e} = [e_R, e_G, e_B]$ is normalized to unit length:
$$\hat{\mathbf{e}} = \frac{\mathbf{e}}{\|\mathbf{e}\|}$$
Pixel values are corrected to a neutral daylight illuminant $[1/\sqrt{3}, 1/\sqrt{3}, 1/\sqrt{3}]$:
$$I_c^{\text{corrected}}(x) = I_c(x) \cdot \frac{1}{\sqrt{3} \cdot \hat{e}_c}$$

### B. Reference-Patch White Balance (High-Precision Calibration)
When the calibrated 18% neutral gray patch on the spacer rim is detected:
1. Sample mean pixel intensities $[\bar{R}_{\text{ref}}, \bar{G}_{\text{ref}}, \bar{B}_{\text{ref}}]$ over the patch ROI.
2. Compute gain factors relative to green:
   $$k_R = \frac{\bar{G}_{\text{ref}}}{\bar{R}_{\text{ref}}}, \quad k_G = 1.0, \quad k_B = \frac{\bar{G}_{\text{ref}}}{\bar{B}_{\text{ref}}}$$
3. Scale every pixel: $R' = k_R \cdot R$, $B' = k_B \cdot B$.

---

## 4. Stage 3: Lesion Localization & ROI Segmentation

Digital spacers capture an internal circular field of view bordered by the matte-black spacer flange. We isolate the clinical lesion from the surrounding physical border:

### A. Spacer Ring & Background Masking
- The spacer contact ring creates a known circular aperture centered at $(x_c, y_c)$ with radius $R_{\text{spacer}} \approx 0.45 \cdot \min(H, W)$.
- A binary circular mask $M_{\text{circ}}(x,y)$ zeroes out all pixels outside the aperture, preventing dark plastic borders from confounding the classifier.

### B. Skin & Lesion Segmentation
- Convert the masked RGB image to the $YC_bC_r$ color space.
- Apply empirical skin chrominance constraints:
  $$77 \le C_b \le 127 \quad \text{and} \quad 133 \le C_r \le 173$$
- Calculate morphological Otsu thresholding within the skin region to segment the darker, erythematous, or hyperpigmented lesion area from normal background skin.
- Apply morphological closing (kernel size $5 \times 5$) to bridge small gaps caused by skin pores or fine hairs.

### C. Aspect-Ratio Preserving Square Bounding Crop
- Compute the bounding box $(x_1, y_1, w_{\text{box}}, h_{\text{box}})$ enclosing the largest connected lesion component.
- Expand to a square of side length $S = \max(w_{\text{box}}, h_{\text{box}}) \times 1.25$ (providing a $25\%$ surrounding healthy margin for context).
- If no discrete focal lesion is found (as in widespread eczema or normal healthy skin), default to the central square crop of the clear aperture.

---

## 5. Stage 4: Standardization for Deep Learning

1. **Spatial Resampling:**
   - Crop the segmented square region and downsample to $224 \times 224$ pixels using **Bicubic Interpolation** (`cv2.INTER_CUBIC`), preserving high-frequency textural patterns (e.g. scales, papules, pigment network).
2. **Dynamic Range Scaling:**
   - Convert `uint8` $[0, 255]$ to `float32` $[0.0, 1.0]$.
3. **Statistical Normalization:**
   - Normalize each color channel using ImageNet population statistics:
     $$x_{\text{norm}}^{(c)} = \frac{x^{(c)} - \mu_c}{\sigma_c}$$
     where $\boldsymbol{\mu} = [0.485, 0.456, 0.406]$ and $\boldsymbol{\sigma} = [0.229, 0.224, 0.225]$.
4. **Memory Layout:**
   - Permute channel ordering from OpenCV $(H, W, C)$ to PyTorch Tensor $(1, C, H, W)$.

---

## 6. Execution Latency Profile (Laptop CPU Benchmark)

| Stage | Operation | CPU Latency (Intel i5/i7) |
|---|---|---|
| **Quality Gate** | Grayscale conversion + cv2.Laplacian + pixel sum | $4.2\text{ ms}$ |
| **Colour Constancy** | Shades-of-Gray Minkowski norm ($p=6$) | $12.5\text{ ms}$ |
| **Lesion Segmentation**| Masking + $YC_bC_r$ thresholding + contour box | $8.1\text{ ms}$ |
| **Resampling & Tensor**| Bicubic resize to $224 \times 224$ + standardization | $2.4\text{ ms}$ |
| **Total Pipeline** | **End-to-End Image Processing** | **$\approx 27.2\text{ ms}$** |

The entire preprocessing sequence consumes under **$30\text{ ms}$** per frame on a standard laptop CPU, ensuring instant response times for mobile health workers.

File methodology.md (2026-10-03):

# ML Methodology (Mobile Clinical Profile)

## 1. Task Definition
Automated multi-class screening of macro skin images captured via smartphone cameras fitted with a 3D-printed optical spacer. The model outputs calibrated probabilities across 6 classes:
1. `eczema` (Atopic Dermatitis)
2. `psoriasis` (Psoriasis)
3. `tinea` (Ringworm / Dermatophytosis)
4. `acne` (Acne Vulgaris)
5. `healthy` (Normal Healthy Skin)
6. `suspicious_lesion` (Neoplastic / Pre-cancerous / Atypical Lesions)

---

## 2. Approach: Transfer Learning on EfficientNet-B0

- **Backbone Selection:** `EfficientNet-B0` pretrained on ImageNet-1k. Chosen for exceptional parameter efficiency (5.3M parameters), rapid CPU inference latency ($< 35\text{ ms}$ on laptop/cloud CPU), and strong macro-feature extraction.
- **Classification Head:** 
  $$\text{Embedding (1280)} \longrightarrow \text{Dropout}(p=0.3) \longrightarrow \text{Linear}(1280, 6) \longrightarrow \text{Logits}$$
- **Training Strategy:**
  - **Phase 1 (Warmup):** Freeze backbone feature layers; train custom classifier head for 3 epochs with AdamW ($\text{lr} = 3 \times 10^{-4}$).
  - **Phase 2 (End-to-End Fine-Tuning):** Unfreeze entire backbone for 20–25 epochs using differential learning rates ($\text{lr}_{\text{backbone}} = 5 \times 10^{-5}$, $\text{lr}_{\text{head}} = 2 \times 10^{-4}$), Cosine Annealing learning rate schedule, and Focal Loss ($\gamma = 2.0$) with class weighting.

---

## 3. Preprocessing & Colour Normalization Pipeline

Mobile smartphone cameras exhibit wide variations in auto-white balance, sensor ISP color tuning, and ambient lighting. Images pass through a structured preprocessing sequence:

```
Raw Mobile Capture
       ↓
Quality Gate (Laplacian blur score ≥ 55, Brightness in [40, 225], Glare ≤ 12%)
       ↓
Colour Constancy (Shades-of-Gray / Reference-Patch White Balance)
       ↓
Lesion Localization & ROI Extraction (Crop out spacer ring & peripheral shadows)
       ↓
Resize to 224 × 224 (Bicubic Interpolation)
       ↓
Standardization (ImageNet Mean [0.485, 0.456, 0.406], Std [0.229, 0.224, 0.225])
```

1. **Colour Constancy:**
   - Evaluates the illuminant colour using the **Shades-of-Gray** algorithm (Minkowski $p$-norm $p=6$):
     $$e(x) = \left( \frac{\int |I(x)|^p dx}{\int dx} \right)^{1/p}$$
   - When a calibrated reference patch is visible within the spacer margin, normalizes RGB channels to align the reference patch with neutral gray ($R=G=B$).
2. **Lesion Localization:**
   - Detects skin foreground against the spacer's matte-black contact boundary using Otsu thresholding in $YC_bC_r$ color space.
   - Extracts the bounding box enclosing the primary lesion and applies a symmetric square crop.

---

## 4. Mobile Domain Data Augmentations

Dermatoscope-specific augmentations (circular vignettes, black contact gel bubbles, simulated dermatoscopy hairs) are removed. In their place, we apply augmentations modeling real smartphone camera dynamics using Albumentations:

| Augmentation Type | Operators | Clinical / Physical Rationale |
|---|---|---|
| **Illumination & White Balance** | `ColorJitter`, `RandomToneCurve`, `RGBShift` | Simulates variations in room lighting (fluorescent, warm LED, daylight). |
| **Shadows & Occlusion** | `RandomShadow`, `CoarseDropout` | Models shadows cast by the smartphone body or health worker's hand. |
| **Optics & Motion** | `GaussianBlur`, `DefocusBlur`, `MotionBlur` | Simulates hand instability or slight defocus during phone positioning. |
| **Geometry** | `RandomRotate90`, `Rotate(degrees=180)`, `Affine(scale=(0.85, 1.15))` | Skin lesions have no canonical orientation; accounts for varying phone angles. |
| **Sensor Noise** | `GaussNoise`, `ImageCompression(quality_range=(75, 95))` | Simulates mobile CMOS sensor grain in dim clinic rooms and JPEG compression. |

---

## 5. Calibration & Temperature Scaling

Raw deep learning models are notoriously overconfident. We calibrate output probabilities via post-hoc **Temperature Scaling**:

1. Logits $z = [z_1, \dots, z_6]$ are scaled by a learned scalar parameter $T > 0$:
   $$P_i = \frac{\exp(z_i / T)}{\sum_j \exp(z_j / T)}$$
2. $T$ is optimized on the held-out validation set to minimize Negative Log-Likelihood (NLL).
3. Evaluated using the **Expected Calibration Error (ECE)** with 10 confidence bins:
   $$\text{ECE} = \sum_{m=1}^{M} \frac{|B_m|}{N} \left| \text{acc}(B_m) - \text{conf}(B_m) \right| \le 0.08$$

---

## 6. Clinical Triage & Decision Logic

To ensure patient safety and practical field utility, the system adheres to strict clinical referral rules:

```
                ┌───────────────────────────────────┐
                │   Calibrated Probabilities P      │
                └─────────────────┬─────────────────┘
                                  │
                 Is P(suspicious_lesion) ≥ 0.25 ?
                                 / \
                                /   \
                              YES    NO
                              /       \
                             ▼         ▼
                 [URGENT REFERRAL]    Is max(P) < 0.50 OR (P₁ - P₂) < 0.10 ?
                 "Suspicious lesion              / \
                  flagged. Prompt               /   \
                  specialist review           YES    NO
                  recommended."               /       \
                                             ▼         ▼
                                    [UNCERTAIN STATE]  [CONFIDENT RESULT]
                                    "Uncertain.        "Possible [Condition].
                                     Consult doctor."   Primary care triage."
```

- **`urgent` Triage Rule:** If $P(\text{suspicious\_lesion}) \ge 0.25$, the application triggers a high-visibility urgent referral notification regardless of whether another condition has higher probability.
- **`uncertain` Abstention Rule:** If highest probability is below $0.50$, or the top two probabilities differ by less than $0.10$ (indicative of look-alike confusion between eczema and psoriasis), the system abstains from declaring a condition and advises manual review.

---

## 7. Explainability (Grad-CAM++)

Grad-CAM++ generates heatmaps on the final convolutional stage (`features[-1]`). This confirms whether the prediction is driven by true biological morphology (e.g., erythematous scaling, follicular comedones, pigment asymmetry) rather than peripheral skin folds, hair, or shadows from the spacer wall.

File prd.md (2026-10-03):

# Product Requirements Document (PRD)

**Product:** E-Dermatologist (Mobile Spacer Edition)  
**Context:** Hackathon problem statement, Somaiya Vidyavihar University with Kaushalya Hospital  
**Status:** Updated Specification v2 (Mobile-First Architecture)

---

## 1. Background
In rural and semi-urban India, access to qualified dermatologists is severely restricted. Frontline health workers (e.g., ASHA workers, community clinic nurses) encounter hundreds of patients with unmanaged or misidentified skin problems. Providing a mobile-based screening tool that pairs everyday smartphones with an inexpensive **3D-printed optical spacer** enables standardized, close-up skin screening without requiring expensive specialized hardware at initial deployment.

---

## 2. Problem Statement
Build an accessible, mobile-first web system that captures standardized skin images using a smartphone fitted with a 3D-printed focal spacer. The system automatically verifies capture quality, normalizes lighting and colour, and classifies the presentation across common skin diseases, healthy skin, or suspicious lesions requiring urgent dermatologist referral.

---

## 3. Goals
1. **Zero-App-Store Friction:** Runs as a responsive Progressive Web App (PWA) accessed over HTTPS on standard mobile browsers (Chrome / Safari).
2. **Standardized Mobile Ingestion:** Leverages a 3D-printed spacer and optional reference patch to fix lens-to-skin distance, eliminate hand tremor focus shifts, and calibrate white balance.
3. **Clinical Triage Classification:** Multi-class classification covering common inflammatory, fungal, acneic, and healthy presentations, plus a high-sensitivity **Suspicious Lesion** triage gate.
4. **Transparent Clinical Uncertainty:** Abstains and flags low-confidence or unclassifiable presentations for direct specialist review rather than guessing.
5. **Fast Mobile-Optimized Inference:** Complete analysis returned to the handset within 2 seconds.

---

## 4. Non-Goals (Hackathon Scope)
- Standalone definitive clinical diagnosis or prescribing prescription drugs.
- Replacing histopathological biopsy or in-person dermatoscope dermatological evaluation.
- Storing personally identifiable patient data or long-term Electronic Medical Records (EMR).
- Classifying ultra-rare dermatological conditions outside the supported taxonomy.

---

## 5. Users & Personas

| Persona | Environment & Role | Key Workflow Needs |
|---|---|---|
| **Community Health Worker (ASHA / Nurse)** | Primary user in field clinics or outreach camps using a smartphone. | One-thumb interface, clear visual positioning cues, zero medical jargon, definitive referral instructions. |
| **Consulting Dermatologist** | Secondary user receiving triaged referrals at Kaushalya Hospital. | Standardized focal distance, colour-calibrated imagery, class probability distribution, quality indicators. |
| **Hackathon Evaluator / Judge** | Evaluating clinical utility, engineering rigor, and deployment feasibility. | Live working demonstration on physical phone hardware with 3D spacer, verifiable metrics, safety guardrails. |

---

## 6. Core User Flow (Mobile Spacer Workflow)

```
[Attach 3D Spacer to Phone]
            ↓
[Open Mobile Web App (HTTPS)] ──> [Automatic Rear Camera Stream Active]
            ↓
[Place Spacer Flush on Skin] ──> [Live Screen: Framing Guide & Lighting Check]
            ↓
[Tap "Capture & Analyze"] ──> [Backend Preprocessing & Inference]
            ↓
[Review Triage Result]
  ├─ Healthy / Reassurance
  ├─ Common Condition (Eczema / Psoriasis / Tinea / Acne)
  ├─ Uncertain (Adjust lighting / re-take / consult doctor)
  └─ Urgent Referral (Suspicious Lesion Alert)
            ↓
[Optional: Export PDF Case Summary for Referral]
```

---

## 7. Supported Conditions (Mobile Clinical Set)

1. **Eczema (Atopic Dermatitis):** Pruritic, erythematous, scaly patches.
2. **Psoriasis:** Well-demarcated erythematous plaques with silvery scaling.
3. **Tinea (Ringworm):** Annular scaly fungal lesions with active erythematous borders.
4. **Acne Vulgaris:** Comedones, papules, pustules, and inflammatory nodules.
5. **Healthy Skin:** Normal physiological skin surface without active disease.
6. **Suspicious Lesion:** Neoplastic or pre-cancerous lesions (Melanoma, BCC, SCC, Actinic Keratosis) triggering immediate specialist referral.

*(Future Phase: Specialized Dermatoscope Modality for fine-grained lesion subtyping).*

---

## 8. Functional Requirements

| ID | Feature | Description | Priority |
|----|---|---|---|
| **F1** | Camera Detection & Environment Selection | Automatically selects rear smartphone camera (`facingMode: environment`) with macro/focus lock. | Must |
| **F2** | Live Spacer Framing Guide | Displays a circular overlay and target reticle matching the 3D spacer internal field of view. | Must |
| **F3** | Connectivity & System Check | One-tap test verifying camera feed, HTTPS handshake, and backend API readiness. | Must |
| **F4** | High-Res One-Touch Capture | Freezes the frame, captures full-resolution JPEG, and uploads to `/api/v1/predict`. | Must |
| **F5** | Quality & Illumination Validation | Server-side validation of blur (Laplacian variance), brightness, and reference patch detection. | Must |
| **F6** | Multi-Class Probability Display | Clear condition card, confidence score, and top-3 probability breakdown. | Must |
| **F7** | Suspicious Lesion Referral Banner | Prominent high-contrast red warning when suspicious lesion probability exceeds safety threshold ($\ge 0.25$). | Must |
| **F8** | Low-Confidence / Abstention State | Amber warning advising physical doctor review when prediction uncertainty is high ($\max P < 0.50$). | Must |
| **F9** | Colour Constancy & Calibration | Automatic Gray-World or reference-patch colour correction before model evaluation. | Should |
| **F10** | Heatmap Lesion Overlay | Optional Grad-CAM++ visualization highlighting morphological regions influencing inference. | Should |
| **F11** | Local Referral PDF Export | Clean 1-page summary including normalized photo, top findings, and clinician disclaimer. | Should |
| **F12** | Image Upload Fallback | Allows uploading a pre-captured photo from phone gallery when live camera cannot be accessed. | Should |
| **F13** | Multilingual UI | English, Hindi, and Marathi localized interfaces. | Could |
| **F14** | Dermatoscope Modality Toggle | Future-proof selector for switching between mobile spacer mode and USB dermatoscope mode. | Could |

---

## 9. Non-Functional Requirements

- **Performance:** Complete round-trip inference in under **2.0 seconds** over 4G/Wi-Fi connection.
- **Mobile Ergonomics:** Single-column layout operable with one thumb; touch target sizes $\ge 48 \times 48\text{ px}$.
- **Security & Privacy:** Mandatory HTTPS; zero persistent storage of patient photographs by default; all EXIF and GPS tags stripped prior to analysis.
- **Portability:** Cross-browser support across mobile Safari (iOS 15+) and mobile Google Chrome (Android 10+).

---

## 10. Success Metrics (Target Acceptance Criteria)

- **Model Performance (on real spacer test images):**
  - Macro-F1 across the 6 classes $\ge 0.78$.
  - Recall for `suspicious_lesion` $\ge 0.90$ (safety priority: false negatives must be minimized).
  - Top-3 accuracy $\ge 0.92$.
  - Expected Calibration Error (ECE) $\le 0.08$.
- **Operational Metrics:**
  - 10 consecutive field captures completed without crash or timeout.
  - First-time frontline worker completes capture flow without training in $< 60$ seconds.

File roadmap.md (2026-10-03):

# Roadmap and Implementation Plan (Mobile-First)

The implementation sequence prioritizes delivering a reliable mobile smartphone screening experience with a 3D-printed spacer, moving specialized dermatoscope hardware to a subsequent multimodal phase.

---

## Team Roles & Ownership

| Role | Core Focus | Primary Deliverables |
|---|---|---|
| **Hardware & Optics Lead** | Smartphone spacer design, 3D printing, reference patch | 3D CAD model, printed spacers, physical calibration |
| **ML & Image Processing Lead** | Data harmonization, model training, colour constancy, calibration | EfficientNet-B0 weights, preprocessing module, ONNX export |
| **Mobile & Backend Lead** | Mobile PWA (React), FastAPI backend, HTTPS ingress | PWA camera interface, REST endpoints, tunnel setup |
| **Clinical QA & Protocol Lead**| Data collection protocol, hospital testing, consent, ethics | Real-camera dataset, model card, referral evaluation |

---

## Phase 0: Hardware Selection & Environmental Setup
- [ ] Select primary smartphone reference model (e.g. Samsung Galaxy / OnePlus / iPhone) and document focal length and lens offset.
- [ ] Design 3D CAD model for the optical spacer cone (fixed height, matte interior, phone mounting clip).
- [ ] 3D print prototype spacer using biocompatible or skin-safe filament (black PLA/PETG).
- [ ] Mount or print a calibrated 18% neutral gray reference patch and 5 mm scale bar onto the spacer perimeter.
- [ ] Set up HTTPS ingress (Cloudflare Tunnel or ngrok) to enable phone camera access to the local development environment.

---

## Phase 1: Mobile Walking Skeleton (PWA + API)
- [ ] Implement responsive mobile-first frontend in React + Vite:
  - Rear camera video stream (`facingMode: environment`).
  - Circular spacer framing guide and central crosshair reticle.
  - Large touch-friendly **Capture & Analyze** button.
- [ ] Implement FastAPI backend endpoints (`/api/v1/health`, `/api/v1/classes`, `/api/v1/predict` with mock output).
- [ ] Verify end-to-end capture on the physical phone over HTTPS in $< 1.5$ seconds.

---

## Phase 2: Mobile Dataset & Baseline Model
- [ ] Download clinical datasets: Fitzpatrick17k, SCIN, PAD-UFES-20, DDI, DermNet.
- [ ] Execute label mapping into the 6 canonical classes (`eczema`, `psoriasis`, `tinea`, `acne`, `healthy`, `suspicious_lesion`).
- [ ] Run perceptual hash deduplication to eliminate cross-split duplicates.
- [ ] Train baseline EfficientNet-B0 with ImageNet transfer learning.
- [ ] Collect first 50 real spacer captures of healthy skin from team members.

---

## Phase 3: Image Processing & Model Fine-Tuning
- [ ] Implement the image processing pipeline:
  - Real-time Laplacian blur quality filter.
  - Shades-of-Gray / reference patch colour constancy.
  - Lesion localization and automatic square ROI cropping.
- [ ] Execute two-stage fine-tuning with mobile augmentations (shadows, white-balance shifts, defocus).
- [ ] Perform post-hoc Temperature Scaling to minimize calibration error (ECE $\le 0.08$).
- [ ] Verify high recall for `suspicious_lesion` ($\ge 0.90$).
- [ ] Export optimized model to ONNX for CPU serving.

---

## Phase 4: Integration, Field Hardening & Triage Rules
- [ ] Connect trained ONNX model and colour pipeline to the FastAPI `/predict` router.
- [ ] Implement clinical triage rule engine:
  - `urgent` referral banner for suspicious lesions ($P \ge 0.25$).
  - `uncertain` abstention banner for low-confidence or look-alike cases.
  - `ok` common condition summary card.
- [ ] Implement optional Grad-CAM++ morphological heatmap toggle.
- [ ] Conduct sanitization and repeatability tests with hospital-grade alcohol wipes on the 3D spacer.

---

## Phase 5: Demo Day Readiness & Multimodal Extension
- [ ] Execute end-to-end demo checklist on physical phone and spacer.
- [ ] Prepare offline sample image gallery as fallback.
- [ ] Generate 1-page PDF referral summary card.
- [ ] **Extension (Multimodal):** Add USB dermatoscope toggle (`modality: "dermatoscope"`) for high-magnification contact imaging.

---

## Milestone Milestones

| Milestone | Deliverable | Success Criteria |
|---|---|---|
| **M1: Mobile Skeleton** | Phone connects over HTTPS, streams camera, captures frame, displays mock results. | Latency $< 1.5\text{ s}$ on phone. |
| **M2: Hardware & Baseline** | 3D spacer printed; phone snaps flush skin photos; baseline 6-class model running. | Focus sharpness verified. |
| **M3: Full Pipeline** | Preprocessing, colour constancy, lesion localization, fine-tuned EfficientNet-B0. | Macro-F1 $\ge 0.78$ on test set. |
| **M4: Demo-Ready** | Real spacer test set evaluated, triage banners validated, 10/10 captures succeed. | Suspicious recall $\ge 0.90$. |
| **M5: Presentation** | Slide deck, live phone demo, physical 3D spacer showcase, model card. | Jury presentation rehearsed. |

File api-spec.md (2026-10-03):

# API Specification (v2.0 Mobile-First)

Base URL: `http://localhost:8000` (or `https://<tunnel-subdomain>.trycloudflare.com`)  
Format: JSON, except `/predict` request (`multipart/form-data`).  
Prefix: `/api/v1`

---

## 1. `GET /api/v1/health`
Verifies backend operational status, model readiness, and active modality.

**Response (200 OK):**
```json
{
  "status": "ok",
  "model_version": "v2.0-mobile-effnetb0",
  "active_modality": "mobile_spacer",
  "num_classes": 6,
  "warmed_up": true
}
```

---

## 2. `GET /api/v1/classes`
Retrieves list of supported clinical conditions, display labels, severity categories, and UI color tokens.

**Response (200 OK):**
```json
{
  "classes": [
    {"id": "eczema", "label": "Eczema", "severity": "common", "color": "#2563EB"},
    {"id": "psoriasis", "label": "Psoriasis", "severity": "common", "color": "#D97706"},
    {"id": "tinea", "label": "Tinea (Ringworm)", "severity": "common", "color": "#7C3AED"},
    {"id": "acne", "label": "Acne", "severity": "common", "color": "#059669"},
    {"id": "healthy", "label": "Healthy Skin", "severity": "normal", "color": "#10B981"},
    {"id": "suspicious_lesion", "label": "Suspicious Lesion", "severity": "urgent", "color": "#DC2626"}
  ]
}
```

---

## 3. `POST /api/v1/predict`
Analyzes a skin photograph captured via mobile smartphone with the 3D-printed spacer.

**Request (`multipart/form-data`):**
| Field | Type | Required | Description |
|---|---|---|---|
| `image` | Binary (JPEG/PNG) | Yes | Full-resolution captured frame (Max 8 MB) |
| `modality` | String | No | `"mobile_spacer"` (default) or `"dermatoscope"` |
| `device_info` | String | No | Client phone model/OS (e.g. `"Samsung_Galaxy_S23_Chrome"`) |
| `capture_height_mm` | Float | No | Focal spacer height in mm (default `35.0`) |
| `heatmap` | Boolean | No | Include base64 Grad-CAM++ heatmap overlay (default `false`) |
| `lang` | String | No | Localized advice text: `"en"` (default), `"hi"`, `"mr"` |

**Response (200 OK) — Confident Finding:**
```json
{
  "request_id": "c7a8b9e1-45f2",
  "modality": "mobile_spacer",
  "prediction": {
    "class_id": "eczema",
    "label": "Eczema",
    "confidence": 0.842,
    "severity": "common"
  },
  "top3": [
    {"class_id": "eczema", "label": "Eczema", "probability": 0.842},
    {"class_id": "psoriasis", "label": "Psoriasis", "probability": 0.098},
    {"class_id": "tinea", "label": "Tinea (Ringworm)", "probability": 0.035}
  ],
  "probabilities": {
    "eczema": 0.842,
    "psoriasis": 0.098,
    "tinea": 0.035,
    "acne": 0.012,
    "healthy": 0.008,
    "suspicious_lesion": 0.005
  },
  "advice": {
    "level": "ok",
    "title": "Features Consistent with Eczema",
    "message": "Presentation aligns with inflammatory eczema. Standard primary care management recommended."
  },
  "quality": {
    "blur_score": 138.4,
    "brightness": 124.0,
    "glare_ratio": 0.02,
    "reference_patch_found": true,
    "colour_cast": "corrected_neutral",
    "status": "good"
  },
  "heatmap_png_base64": null,
  "model_version": "v2.0-mobile-effnetb0",
  "latency_ms": 38.5
}
```

**Response (200 OK) — Urgent Referral Triage (Suspicious Lesion):**
```json
{
  "request_id": "e9f0d1a2-83b4",
  "modality": "mobile_spacer",
  "prediction": {
    "class_id": "suspicious_lesion",
    "label": "Suspicious Lesion",
    "confidence": 0.761,
    "severity": "urgent"
  },
  "top3": [
    {"class_id": "suspicious_lesion", "label": "Suspicious Lesion", "probability": 0.761},
    {"class_id": "psoriasis", "label": "Psoriasis", "probability": 0.145},
    {"class_id": "eczema", "label": "Eczema", "probability": 0.062}
  ],
  "advice": {
    "level": "urgent",
    "title": "Specialist Review Required",
    "message": "Morphological features warrant formal in-person examination by a dermatologist. Facilitate referral."
  },
  "quality": {
    "blur_score": 152.0,
    "brightness": 115.0,
    "glare_ratio": 0.01,
    "reference_patch_found": true,
    "colour_cast": "corrected_neutral",
    "status": "good"
  },
  "heatmap_png_base64": "data:image/png;base64,iVBORw0KGgoAAAANS...",
  "latency_ms": 42.0
}
```

---

## 4. Error Responses

```json
{
  "error": {
    "code": "image_too_blurry",
    "message": "Image is out of focus. Ensure the spacer is resting flat against the skin and hold phone steady.",
    "details": {
      "blur_score": 28.6,
      "min_required": 55.0
    }
  }
}
```

| HTTP Status | Error Code | Description / Remedy |
|---|---|---|
| **400** | `invalid_request` | Missing image payload or malformed multipart data. |
| **413** | `file_too_large` | File exceeds maximum upload limit ($> 8\text{ MB}$). |
| **415** | `unsupported_media_type` | File is not JPEG, PNG, or WEBP. |
| **422** | `image_too_blurry` | Focus below threshold ($< 55.0$). Hold phone steady. |
| **422** | `image_too_dark` | Inadequate ambient illumination ($< 40$). Increase room lighting. |
| **422** | `spacer_misaligned` | Severe uneven light leakage or background detected. |
| **503** | `model_not_ready` | Model weights still loading or undergoing warmup. |

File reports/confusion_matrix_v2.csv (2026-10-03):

eczema | psoriasis | tinea | acne | healthy | suspicious_lesion
94 | 17 | 12 | 0 | 0 | 10
15 | 75 | 8 | 3 | 0 | 7
11 | 8 | 126 | 0 | 0 | 11
2 | 1 | 3 | 78 | 0 | 4
0 | 0 | 0 | 0 | 230 | 2
4 | 5 | 7 | 2 | 1 | 191

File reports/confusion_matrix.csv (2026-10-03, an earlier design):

actual_predicted | eczema | psoriasis | tinea | acne | healthy | suspicious_lesion
eczema | 96 | 17 | 11 | 4 | 0 | 5
psoriasis | 29 | 62 | 8 | 8 | 0 | 1
tinea | 38 | 18 | 89 | 3 | 3 | 5
acne | 2 | 3 | 1 | 78 | 1 | 3
healthy | 0 | 0 | 1 | 0 | 231 | 0
suspicious_lesion | 16 | 22 | 11 | 8 | 2 | 151

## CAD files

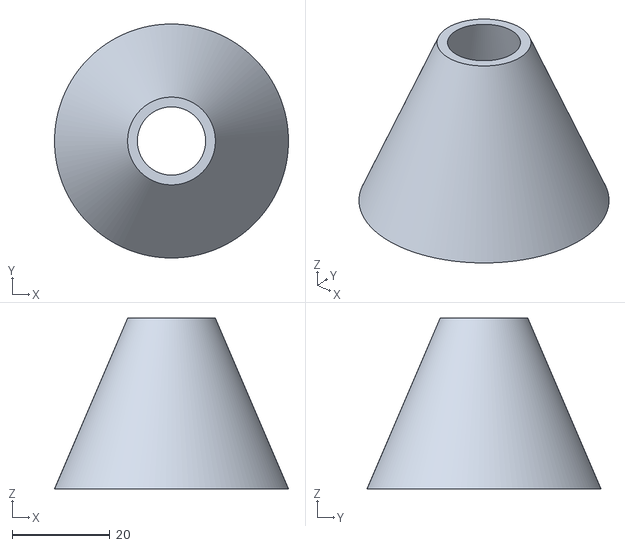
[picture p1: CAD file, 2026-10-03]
hardware/stl/spacer_35mm.stl
48.0 x 48.0 x 35.0

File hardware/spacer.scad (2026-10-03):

// Parametric Optical Spacer - E-Dermatologist (Mobile Spacer Edition)
// Auto-generated by hardware/spacer_generator.py
// Units: millimetres. Render with F6 then export STL.

HEIGHT        = 35.0;
TOP_APERTURE  = 14.0;
BASE_CLEAR    = 38.0;
BASE_OUTER    = 48.0;
WALL_TOP      = 2.0;
SEG           = 128;

module spacer() {
    difference() {
        // Outer body: widening base flange tapering to the camera aperture.
        cylinder(h = HEIGHT,
                 d1 = BASE_OUTER,
                 d2 = TOP_APERTURE + 2 * WALL_TOP,
                 $fn = SEG);
        // Inner cavity: clear optical path.
        translate([0, 0, -0.01])
            cylinder(h = HEIGHT + 0.02,
                     d1 = BASE_CLEAR,
                     d2 = TOP_APERTURE,
                     $fn = SEG);
    }
}

spacer();

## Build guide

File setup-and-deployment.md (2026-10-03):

# Setup, Deployment & Mobile HTTPS Configuration

## 1. Prerequisites
- **Computer/Laptop:** Python 3.10+, Node.js 18+, Git.
- **Smartphone:** iOS (Safari 15+) or Android (Chrome 100+).
- **Physical Hardware:** 3D-printed optical spacer (matching phone camera dimensions) with contact reference patch.
- **Network Tunnel Tool:** Cloudflare Tunnel (`cloudflared`) or `ngrok` (required for mobile HTTPS camera permissions).

---

## 2. Why HTTPS is Mandatory for Mobile Devices
Modern mobile browsers (Chrome on Android and Safari on iOS) **strictly enforce HTTPS** for hardware camera access (`navigator.mediaDevices.getUserMedia`). 
While desktop browsers allow unencrypted camera access on `http://localhost`, your phone connecting over your local network (e.g. `http://192.168.1.5:5173`) will **refuse camera permissions**.

To connect your physical smartphone camera to your development server, you must expose an HTTPS endpoint.

---

## 3. Recommended Development Ingress: Cloudflare Tunnel (Free & Instant)

Cloudflare Tunnel provides a secure, encrypted HTTPS URL directly to your local laptop without opening router ports or buying SSL certificates:

1. **Install Cloudflare Tunnel:**
   - Windows (via winget or direct binary):
     ```powershell
     winget install Cloudflare.cloudflared
     ```
   - macOS / Linux:
     ```bash
     brew install cloudflared   # or apt-get install cloudflared
     ```
2. **Start Frontend & Backend on Laptop:**
   ```bash
   # Terminal 1: Backend
   cd backend && uvicorn app.main:app --reload --port 8000

   # Terminal 2: Frontend
   cd frontend && npm run dev -- --host 0.0.0.0 --port 5173
   ```
3. **Expose Frontend over HTTPS:**
   ```bash
   # Terminal 3: Tunnel to Vite Dev Server
   cloudflared tunnel --url http://localhost:5173
   ```
   *Cloudflare outputs a public URL: `https://xxxx-xxxx.trycloudflare.com`.*
4. **Open the URL on Your Smartphone:**
   - Scan the terminal QR code or open the `https://...` link in mobile Chrome/Safari.
   - The browser will ask for camera permission and open the rear camera feed immediately!

*(Alternative: `ngrok http 5173` achieves the same result).*

---

## 4. Phone & 3D Spacer Setup Protocol

1. **Lens Alignment:**
   - Slide the phone into the 3D-printed cradle. Ensure the primary rear camera lens is perfectly concentric with the spacer cone aperture.
   - If using a multi-lens phone (e.g., iPhone 14/15 Pro, Samsung S23/S24), ensure the primary 1x wide lens is used (macro auto-switching should be locked in camera settings).
2. **Lens Hygiene:**
   - Wipe the phone camera lens with a microfiber cloth before inserting into the cradle to prevent flare or hazy focus.
3. **Contact Hygiene:**
   - Wipe the skin-contact ring of the spacer with a 70% isopropyl alcohol wipe between each patient. Allow 15 seconds to air dry.
4. **Flash & Lighting:**
   - Keep phone LED flash disabled to prevent blinding specular reflections. Rely on ambient room lighting diffusing through the spacer side ports or integrated diffuse LED.

---

## 5. Local Codebase Setup

```bash
# Clone repository
git clone <repo-url> e-dermatologist && cd e-dermatologist

# Backend Setup
cd backend
python -m venv .venv
source .venv/bin/activate    # On Windows: .venv\Scripts\activate
pip install -r requirements.txt

# Frontend Setup
cd ../frontend
npm install
```

---

## 6. Environment Variables (`.env`)

| Variable | Example | Description |
|---|---|---|
| `MODEL_PATH` | `models/model.onnx` | Path to trained EfficientNet-B0 ONNX weights |
| `CLASSES_PATH` | `configs/classes.yaml` | Class names and triage thresholds |
| `MAX_UPLOAD_MB` | `8` | Maximum image size limit |
| `ALLOWED_ORIGINS` | `*` | Allowed CORS origins (set to tunnel URL or `*` for testing) |
| `VITE_API_URL` | `https://api-tunnel.trycloudflare.com/api/v1` | URL for mobile PWA to reach backend |

---

## 7. Cloud Deployment (Backup for Hackathon Jury)

If presenting in an auditorium with unreliable local Wi-Fi, host the backend in a container on Google Cloud Run, Render, or Railway:

```dockerfile
# backend/Dockerfile
FROM python:3.11-slim
WORKDIR /app
RUN apt-get update && apt-get install -y libgl1-mesa-glx libglib2.0-0 && rm -rf /var/lib/apt/lists/*
COPY requirements.txt .
RUN pip install --no-cache-dir -r requirements.txt
COPY . .
EXPOSE 8000
CMD ["uvicorn", "app.main:app", "--host", "0.0.0.0", "--port", "8000"]
```
Deploy the frontend static bundle to Vercel or Netlify with HTTPS enabled by default.

---

## 8. Mobile Troubleshooting

| Symptom | Cause | Solution |
|---|---|---|
| **Camera permission prompt not appearing** | Connecting over plain `http://<ip>` | Must access via an HTTPS URL (Cloudflare Tunnel or ngrok). |
| **Image is black or obstructed** | Wrong rear lens selected on multi-camera phone | Tap camera switch icon or adjust phone position in spacer cradle. |
| **Blurry live preview** | Phone autofocus hunting or closer than minimum focal distance | Ensure 3D spacer height ($\ge 35\text{ mm}$) matches the phone camera minimum focal length. |
| **Severe colour cast** | Fluorescent or warm yellow bulb | Enable automatic colour constancy; position reference patch in frame. |

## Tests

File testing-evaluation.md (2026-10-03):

# Testing and Evaluation Protocol (Mobile Spacer)

## 1. Test Layers

| Layer | Target System | Methodology & Tools |
|---|---|---|
| **Unit (Backend)** | Preprocessing, blur metrics, colour constancy, calibration | `pytest`, synthetic test image matrices |
| **Unit (Mobile PWA)** | Camera stream, spacer framing reticle, one-touch capture | `Vitest`, React Testing Library, mock camera streams |
| **API Contract** | Multipart upload, schema compliance, HTTP error codes | `pytest`, `httpx` test client |
| **Model Benchmark** | Performance across Fitzpatrick skin types and test sets | `ml/src/eval.py`, scikit-learn, confusion matrices |
| **Real Hardware Gate**| End-to-end evaluation on physical phone + 3D spacer captures | Held-out real spacer test set (100+ images) |

---

## 2. Model Evaluation Metrics & Acceptance Criteria

| Metric | Target Criterion | Clinical & Operational Rationale |
|---|---|---|
| **Macro-F1 (6 classes)** | $\ge 0.78$ | Balanced performance across common and rare classes. |
| **Recall for `suspicious_lesion`** | **$\ge 0.90$** | **Highest Safety Priority:** False negatives on potential malignancies must be minimized. |
| **Top-3 Accuracy** | $\ge 0.92$ | Clinical utility in differentiating look-alike conditions (e.g. Eczema vs Psoriasis). |
| **Calibration (ECE)** | $\le 0.08$ | Ensures confidence percentages match empirical probability. |
| **End-to-End Latency** | $\le 1.8\text{ s}$ | Smooth user experience over 4G mobile networks. |
| **Demo Stability** | 10 of 10 consecutive captures succeed | Zero app crashes or camera disconnects during demonstration. |

---

## 3. Subgroup & Fairness Audit

Performance must not degrade across varied skin tones or anatomical regions:
- **Fitzpatrick Subgroups:** Evaluate per-class precision and recall separately for:
  - FST I–II (Fair / Light)
  - FST III–IV (Medium / Olive)
  - FST V–VI (Deep / Dark)
- **Acceptance Gate:** Recall for `suspicious_lesion` must remain $\ge 0.88$ across every evaluated Fitzpatrick cohort.
- **Anatomical Slices:** Assess consistency across forearm, dorsal hand, torso, and face.

---

## 4. Robustness Stress Tests

Evaluate accuracy degradation under real-world mobile imperfections:
1. **Defocus Blur:** Apply Gaussian blur ($\sigma \in [1.0, 3.0]$) to simulate spacer displacement.
2. **Colour Temperature Casts:** Shift illuminant white point from $3000\text{ K}$ (warm tungsten) to $6500\text{ K}$ (cool daylight); confirm colour constancy algorithm maintains predictions within $5\%$ probability delta.
3. **Sensor Noise:** Add Gaussian and salt-and-pepper noise corresponding to ISO 800+ mobile shots.

---

## 5. Demo-Day Physical Hardware Checklist

Prior to entering the demonstration room:

### Physical Hardware
- [ ] Primary smartphone charged to $> 80\%$; screen brightness locked to $75\%$.
- [ ] 3D-printed optical spacer inspected:
  - Phone mount snaps firmly without slipping.
  - Interior matte-black finish is clean with no glossy reflection spots.
  - Contact rim is smooth and crack-free.
- [ ] Calibrated reference patch is firmly affixed and clean.
- [ ] Hygiene kit: Pack of hospital-grade 70% isopropyl alcohol wipes.
- [ ] Backup smartphone with identical cradle mount available.

### Software & Connectivity
- [ ] Backend server running locally on laptop (`uvicorn app.main:app`).
- [ ] Model warmed up with dummy inference call (`/health` reports `warmed_up: true`).
- [ ] Cloudflare Tunnel active (`cloudflared tunnel --url http://localhost:5173`); HTTPS link loaded and bookmarked on the phone.
- [ ] Camera permissions granted in mobile browser.
- [ ] Completed 3 trial captures on team member skin.
- [ ] Emergency fallback: Offline sample gallery button loaded in the web app.
